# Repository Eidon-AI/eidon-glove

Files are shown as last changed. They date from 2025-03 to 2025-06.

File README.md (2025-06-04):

# eidon-glove

A robust 16-DOF hand/finger tracking wearable standard Bluetooth Human Interface Device (BLE HID) designed for humanoid teleoperation and collecting embodied AI training datasets.

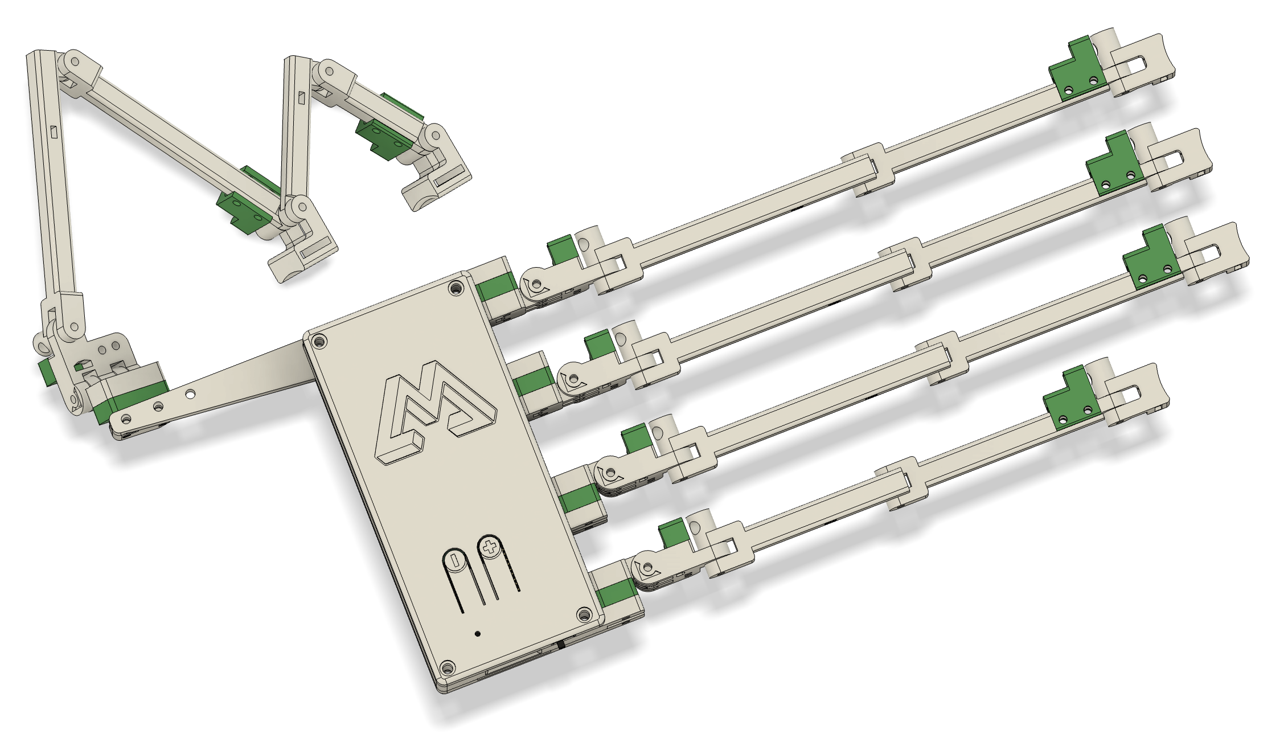
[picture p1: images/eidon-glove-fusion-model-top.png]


## Features

- **16-DOF Finger Tracking**: Full hand tracking with 16 Hall effect sensors for precise joint angle measurement
- **Wireless Connectivity**: Standard BLE HID protocol (~100Hz wireless transmission)
- **Multi-Mode Support**: Generic HID and gamepad modes with custom firmware
- **9-DOF Orientation Tracking**: Optional BNO085 IMU integration (Accelerometer/Gyro/Magnetometer)
- **Custom Hardware**: Purpose-built PCB with analog multiplexer for efficient sensor management
- **ESP32-C3 MCU**: Built-in BLE, WiFi, and battery charging capabilities
- **All-Day Battery**: 3.7V 2000mAh lithium polymer battery with power management
- **Wearable Design**: Fully 3D printable exoskeleton optimized for comfort and accuracy
- **Power Management**: Integrated power switch and LED status indicators

## Hardware Architecture

### Core Components
- **Microcontroller**: Seeed XIAO ESP32-C3 (RISC-V 32-bit @ 160MHz)
- **Sensors**: 16x Hall effect sensors + magnets for joint tracking
- **IMU**: BNO085 9-DOF sensor (optional)
- **Multiplexer**: Analog multiplexer for sensor input management
- **Battery**: 3.7V 2000mAh Li-Po with ETA4054S2F charging chip

### BOM
- Seeed XIAO ESP32-C3 [[Amazon](https://amzn.to/43tHIOO)]
- Hall Effect Sensor [[Amazon](https://amzn.to/4mQyvrq)]
- BNO085 IMU Module [[Amazon](https://amzn.to/3ZKFbNI)]
- Adjustable Hand Strap [[Amazon](https://amzn.to/4mLNEds)]
- Finger Velcro Loops [[Amazon](https://amzn.to/4kuzVpS)]
- Wire Zip Ties [[Amazon](https://amzn.to/4mFPDQp)]
- M2 Screws [[Amazon](https://amzn.to/45LmPQm)]
- Lipo Battery [[Amazon](https://amzn.to/3ZLaW9m)]
- Power Switch [[Amazon](https://amzn.to/4kTvcxY)]
- Status LED [[Amazon](https://amzn.to/43XH38d)]
- JST Connectors + Wires [[AliExpress](https://www.aliexpress.us/item/3256807031812901.html)] *(only if using custom PCB)*
- Multiplexer Module [[Amazon](https://amzn.to/3HiPO4a)] *(only if **NOT** using custom PCB)*

### Pin Configuration (XIAO ESP32-C3)

| Function | GPIO | Pin Label | Notes |
|---|---|---|---|
| **Multiplexer Control** |
| S0 | 10 | D10 | Multiplexer select bit 0 |
| S1 | 9 | D9 | Multiplexer select bit 1 |
| S2 | 6 | D4 | Multiplexer select bit 2 |
| S3 | 7 | D5 | Multiplexer select bit 3 |
| **User Interface** |
| Boot Button | 9 | D9 | Built-in XIAO button |
| Mode Button | 10 | D10 | PCB-mounted button |
| Status LED | 5 | D3 | Power/status indicator |
| **BNO085 IMU (Optional)** |
| I2C SDA | 21 | D6/TX | IMU data line |
| I2C SCL | 20 | D7/RX | IMU clock line |

## BNO085 IMU Integration (Optional)

The BNO085 9-DOF IMU provides orientation tracking to complement finger position data. This is an optional component that can be added for enhanced hand tracking capabilities.

### BNO085 Wiring

**I2C Connection:**
- **SDA**: GPIO 21 (D6/TX) - I2C Data line
- **SCL**: GPIO 20 (D7/RX) - I2C Clock line  
- **VCC**: 3.3V power supply
- **GND**: Ground connection
- **I2C Address**: 0x4B (default)

**Optional Connections:**
- **RST**: Not currently implemented (software reset used instead)
- **INT**: Interrupt pin (not used in current implementation)

### Important Notes

⚠️ **Multiplexer Pin Conflicts**: The current codebase has these remaining pin assignment conflicts:

1. **Button Conflicts**: Boot button (GPIO 9) and Mode button (GPIO 10) conflict with multiplexer pins S1 and S0

### BNO085 Software Configuration

The IMU is configured for:
- **Sensor Fusion**: Game Rotation Vector mode
- **Update Rate**: 200Hz (5ms intervals)  
- **Auto-Detection**: System continues operation if IMU is not connected
- **Data Output**: Quaternion format for orientation representation

Breakout Board Recommendation:

- GY-BNO085 Module [[Amazon](https://www.amazon.com/Teyleten-Robot-BNO085-Accuracy-Nine-Axis/dp/B0CL26J81F)]

## Getting Started

### Prerequisites
- PlatformIO IDE extension
- 3D printer for mechanical components
- PCB manufacturing (or breadboard for prototyping)
- Components listed in BOM (see PCB directory)

### Build Instructions
1. Clone this repository
2. Open firmware project in PlatformIO
3. Install dependencies (automatically handled by platformio.ini)
4. Build and upload to XIAO ESP32-C3
5. Assemble mechanical components
6. Calibrate sensors using built-in calibration mode

### Firmware Dependencies
- **ResponsiveAnalogRead** ^1.2.1: Sensor input filtering  
- **NimBLE-Arduino** ^1.4.1: Bluetooth Low Energy
- **Adafruit BNO08x** ^1.2.3: IMU sensor library

## Web Hand Visualizer

The eidon-glove includes a comprehensive web-based visualizer for real-time hand tracking data visualization and analysis.

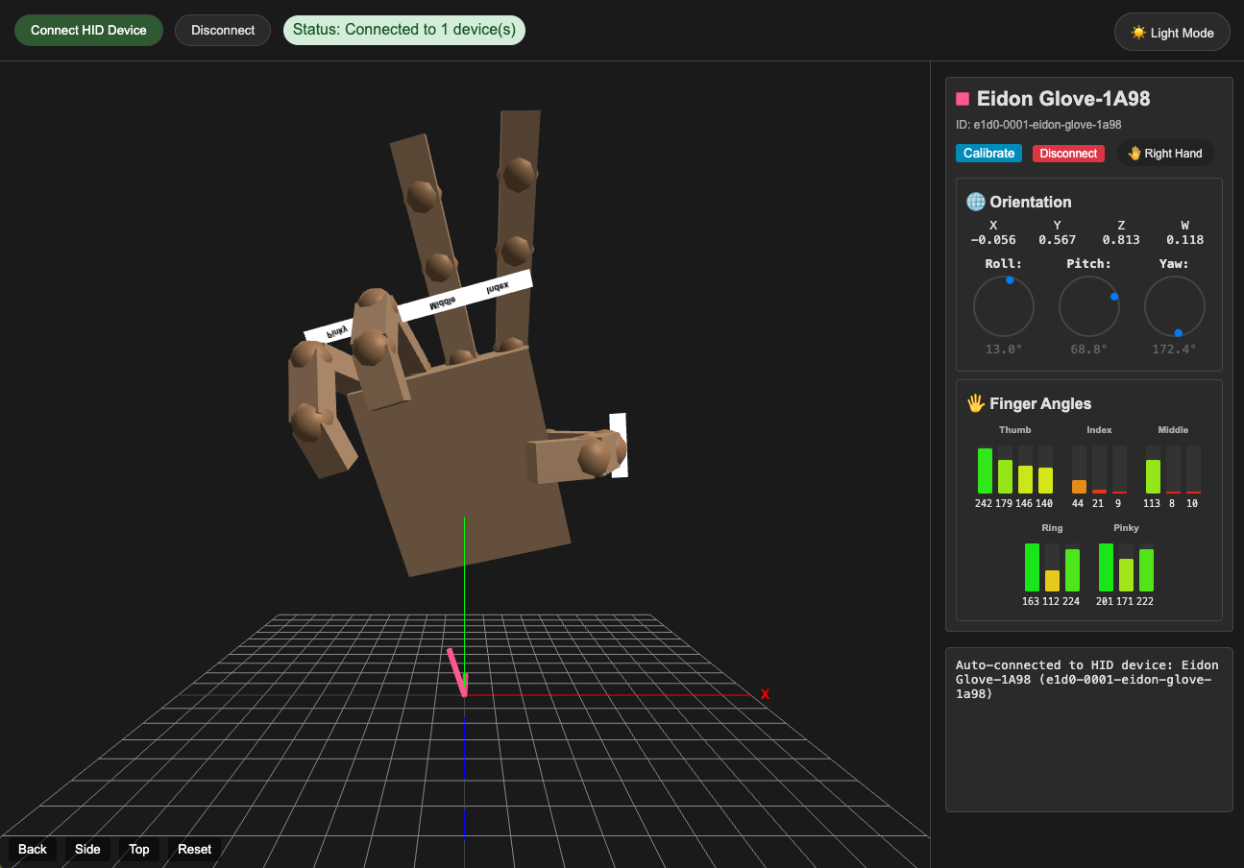
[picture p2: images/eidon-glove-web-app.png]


### What It Is

A browser-based 3D hand visualization tool that:
- **Real-time 3D Hand Model**: Displays a detailed 3D hand that mirrors your glove movements
- **IMU Orientation Tracking**: Shows precise hand orientation using quaternion data from the BNO085 IMU
- **16-DOF Finger Tracking**: Visualizes all finger joint movements with color-coded angle displays
- **Multi-Device Support**: Can connect to multiple gloves and trackers simultaneously
- **Data Recording & Playback**: Record hand movements and play them back for analysis

### Key Features

- **🎯 Gimbal-Lock Free**: Stable orientation tracking without axis flipping at extreme angles
- **🔄 Auto-Reconnect**: Automatically reconnects to previously paired devices on page refresh  
- **🎨 Color-Coded Visualization**: Device-specific colors for easy identification
- **📊 Real-Time Data**: Live quaternion values, Euler angles, and joint positions
- **🎮 HID Protocol**: Uses standard Web HID API for direct browser connection
- **💾 Session Recording**: Capture and save hand movement sequences

### How to Use

1. **Open the Web App**: Navigate to `/web/index.html` in a modern browser (Chrome/Edge recommended)
2. **Connect Your Glove**: Click "Connect" and select your eidon-glove from the HID device list
3. **Calibrate**: Use the "Calibrate" button to zero the sensor baseline
4. **Visualize**: Watch the 3D hand model mirror your real hand movements in real-time

### Browser Requirements

- **Chrome 89+** or **Edge 89+** (Web HID API support required)
- **HTTPS Connection** (required for Web HID API)
- **Modern GPU** (WebGL support for 3D rendering)

### Technical Details

- **Communication**: Web HID API for direct glove communication
- **3D Rendering**: Three.js for WebGL-based hand visualization  
- **Coordinate System**: Optimized quaternion mapping `(x, z, -y, w)` for stable orientation
- **Update Rate**: ~60fps visualization with real-time sensor data
- **Data Format**: 24-byte HID reports containing joint angles + quaternion data

### Files

```
web/

```

The web visualizer provides an intuitive way to validate glove functionality, debug sensor issues, and demonstrate the full capabilities of the eidon-glove system.

## Project Structure

```
eidon-glove/
├── firmware/          # ESP32-C3 firmware (PlatformIO)
│   ├── src/           # Main source code
│   ├── lib/           # Custom libraries
│   └── platformio.ini # Build configuration
├── pcb/               # KiCad PCB design files
├── cad/               # 3D printable components
├── web/               # Web interface (if applicable)
│   ├── index.html         # Main web interface
│   ├── script.js          # Core visualization logic
│   ├── style.css          # UI styling
│   ├── tetris.html    # Simple Tetris game demo
│   └── piano.html     # Simple five key piano demo
└── images/            # Documentation images
```

## Inspired By

This project builds upon excellent open-source work:
- **[Project-Homunculus](https://github.com/nepyope/Project-Homunculus)**: Original 3D models and mechanical design
- **[finger-tracker](https://github.com/max-titov/finger-tracker)**: Original firmware architecture
- **[glove-v3](https://github.com/max-titov/glove-v3)**: Current PCB design foundation

## Contributing

Contributions are welcome! Please:
1. Fork the repository
2. Create a feature branch
3. Make your changes
4. Test thoroughly
5. Submit a pull request

## License

This project is released under an open-source license. See individual component repositories for specific licensing terms.

---

**Status**: Active development - hardware tested, firmware functional, documentation in progress.

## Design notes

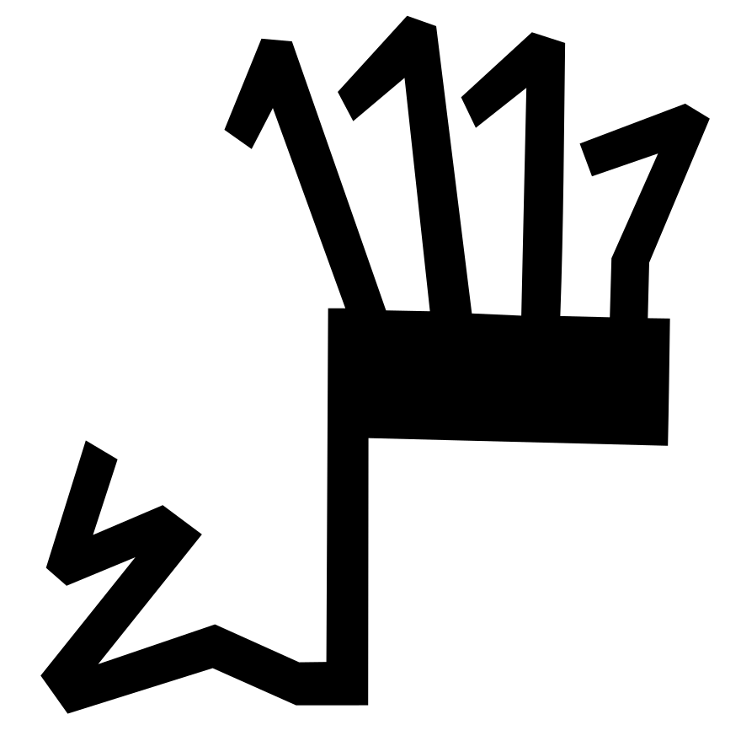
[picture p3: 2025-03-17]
pcb/graphics/glove-v1.png

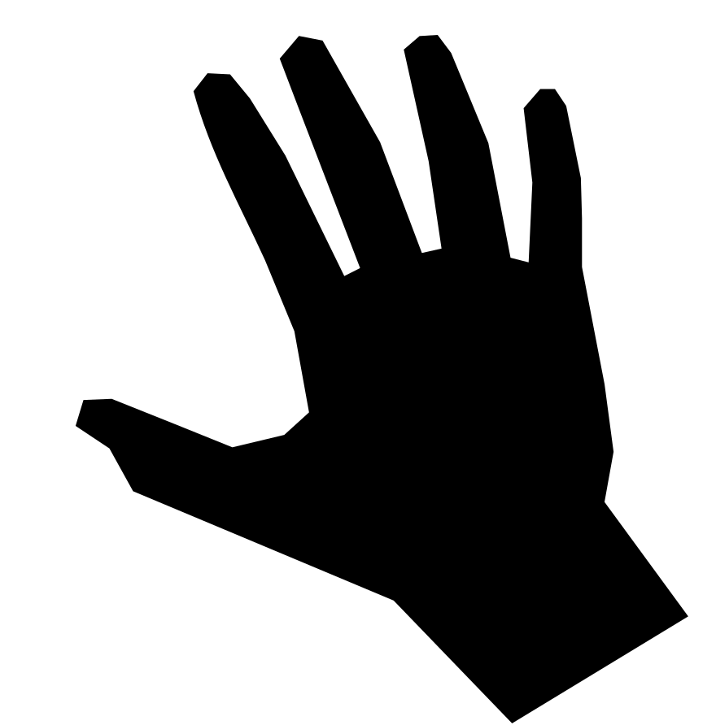
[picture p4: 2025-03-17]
pcb/graphics/hand.png

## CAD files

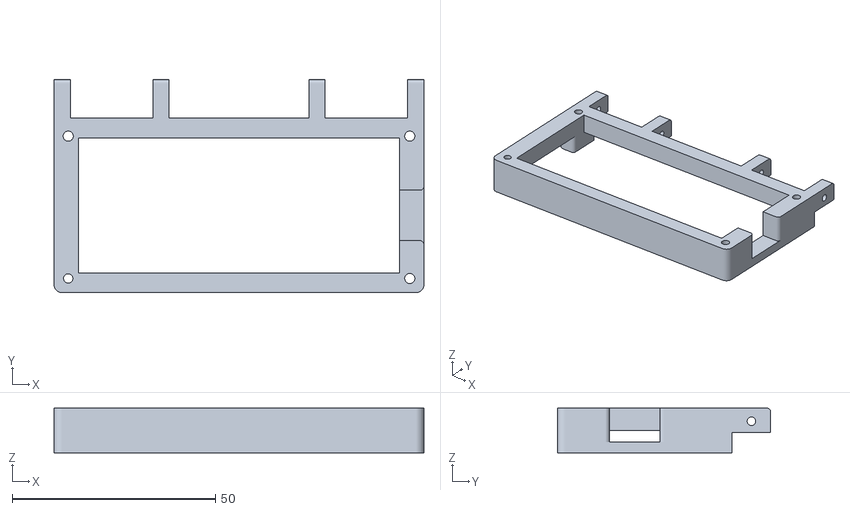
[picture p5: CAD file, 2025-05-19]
cad/palm_body.stl
91.0 x 52.5 x 11.1

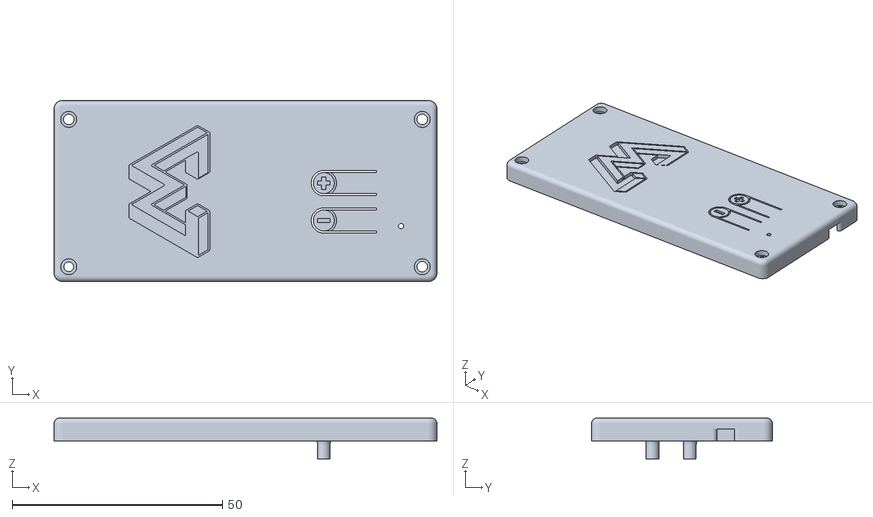
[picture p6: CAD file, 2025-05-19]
cad/palm_lid.stl
91.0 x 43.0 x 9.71

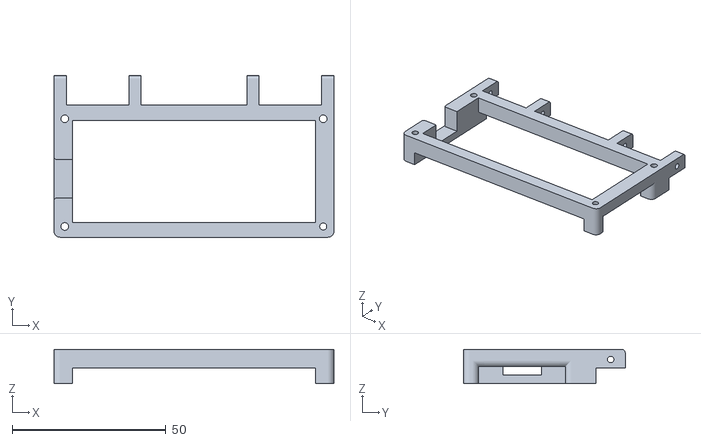
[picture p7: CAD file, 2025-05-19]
cad/palm_body_left.stl
91.0 x 52.5 x 11.1

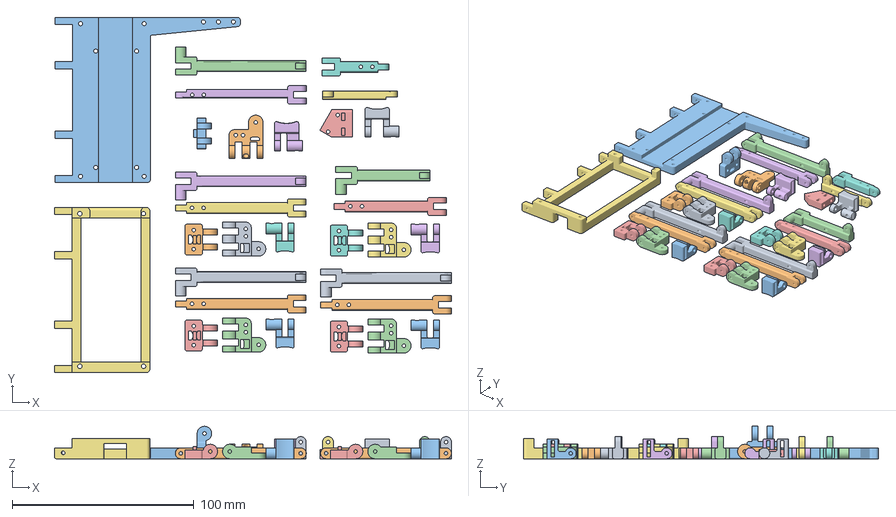
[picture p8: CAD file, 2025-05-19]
cad/EIDON_GLOVE_LEFT.3mf
218.5 x 195.5 x 17.9 mm
finger_pip_1.stl x 4
finger_pip_2.stl x 3
finger_dip_2.stl x 4
finger_mcp_3.stl x 4
finger_mcp2.stl x 4
palm_base.stl
thumb_mcp_holder.stl
thumb_pip_2.stl
thumb_ip_1.stl
thumb_ip_2.stl
thumb_ip_3.stl
thumb_mcp_3.stl
thumb_mcp_2.stl
pinky_pip_1.stl
pinky_pip_2.stl
thumb_dip_2.stl
palm_lid_alt.stl

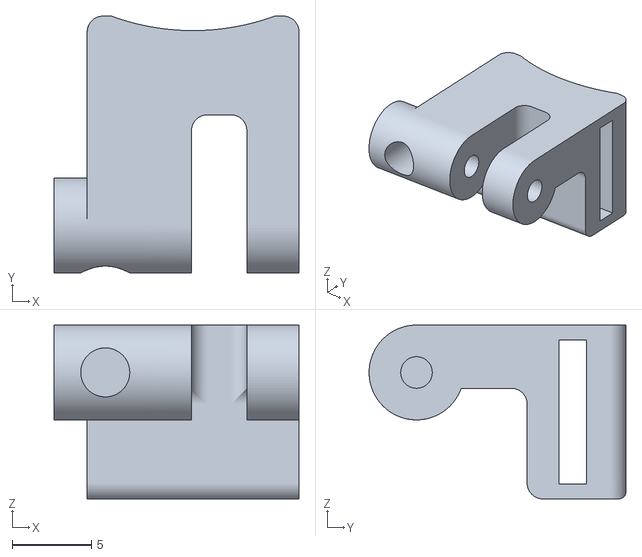
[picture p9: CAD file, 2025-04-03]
cad/thumb_dip_2.stl
15.5 x 16.2 x 11.0

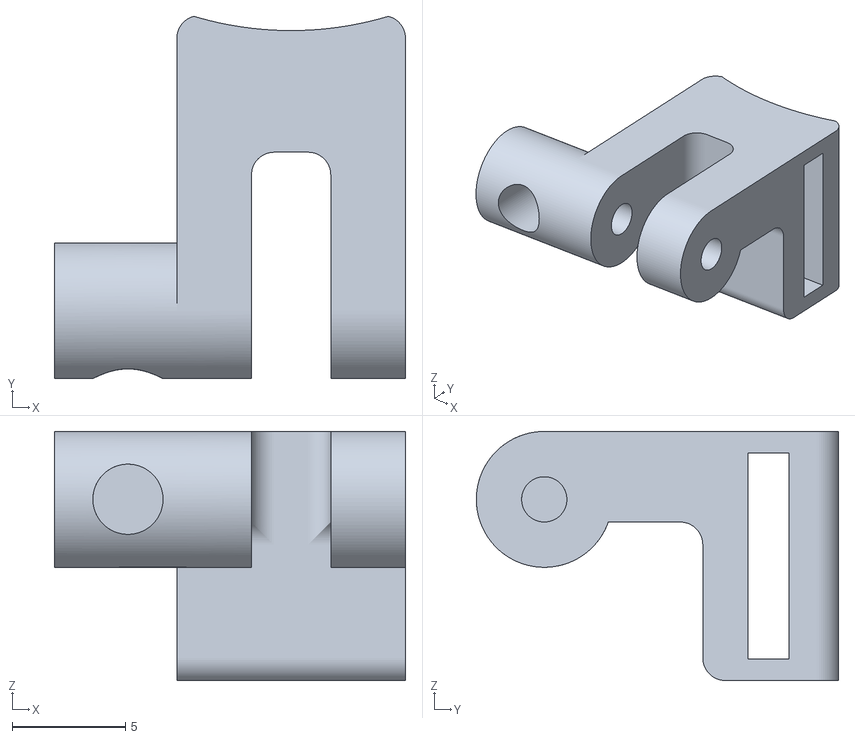
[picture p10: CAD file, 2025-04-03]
cad/finger_dip_2.stl
15.5 x 16.0 x 11.0

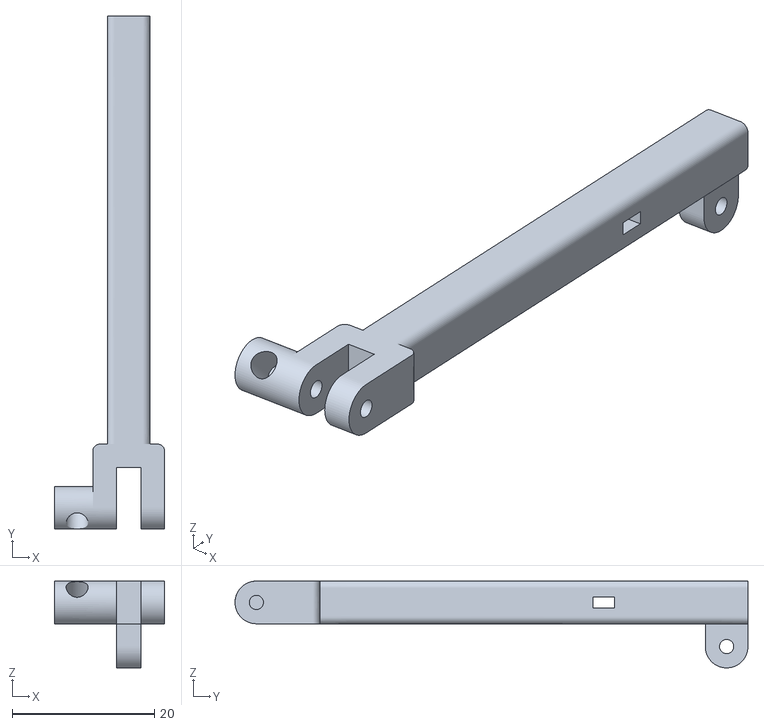
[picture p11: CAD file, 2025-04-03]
cad/thumb_pip_1.stl
15.5 x 72.1 x 12.2

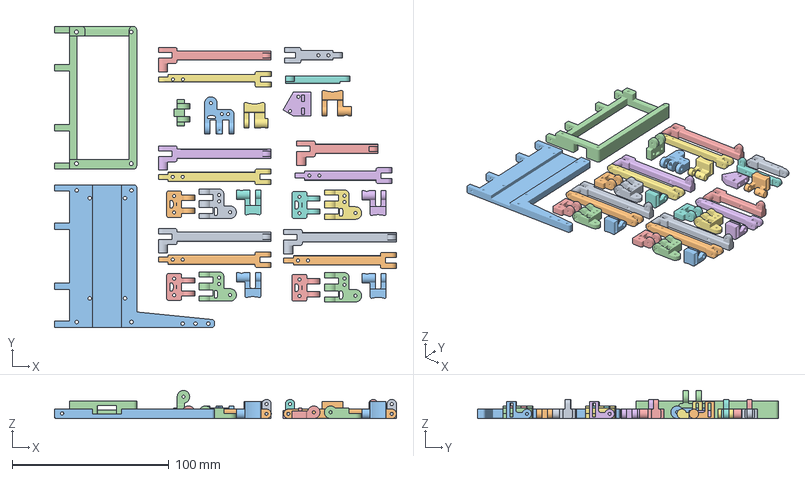
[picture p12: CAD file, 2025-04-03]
cad/EIDON_GLOVE_RIGHT.3mf
218.3 x 192.1 x 17.9 mm
finger_pip_1.stl x 4
finger_pip_2.stl x 3
finger_dip_2.stl x 4
finger_mcp_3.stl x 4
finger_mcp2.stl x 4
palm_base.stl
palm_lid.stl
thumb_mcp_holder.stl
thumb_pip_2.stl
thumb_ip_1.stl
thumb_ip_2.stl
thumb_ip_3.stl
thumb_mcp_3.stl
thumb_mcp_2.stl
pinky_pip_1.stl
pinky_pip_2.stl
thumb_dip_2.stl

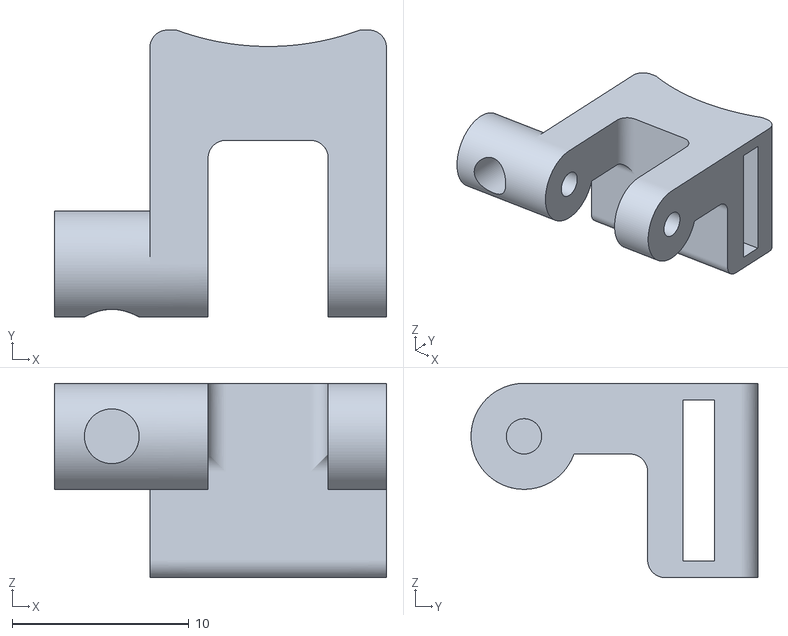
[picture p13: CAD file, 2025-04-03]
cad/thumb_ip_3.stl
18.8 x 16.2 x 11.0

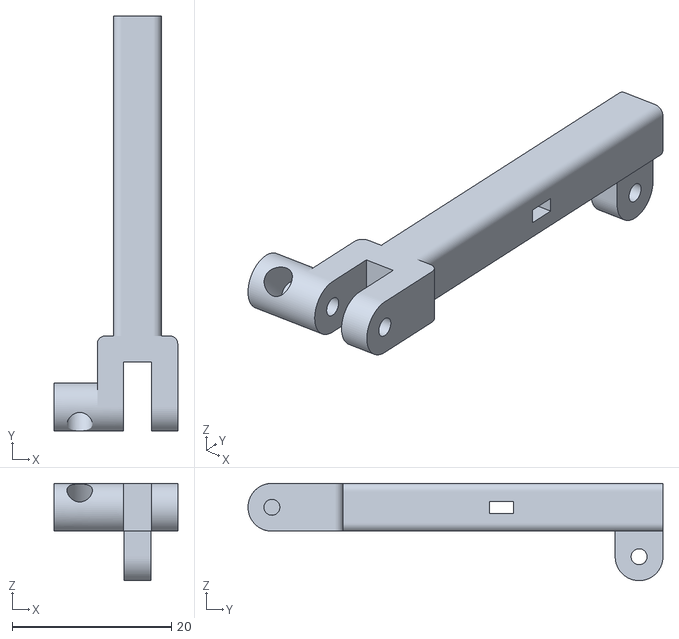
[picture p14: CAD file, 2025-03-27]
cad/pinky_pip_1.stl
15.5 x 52.1 x 12.2

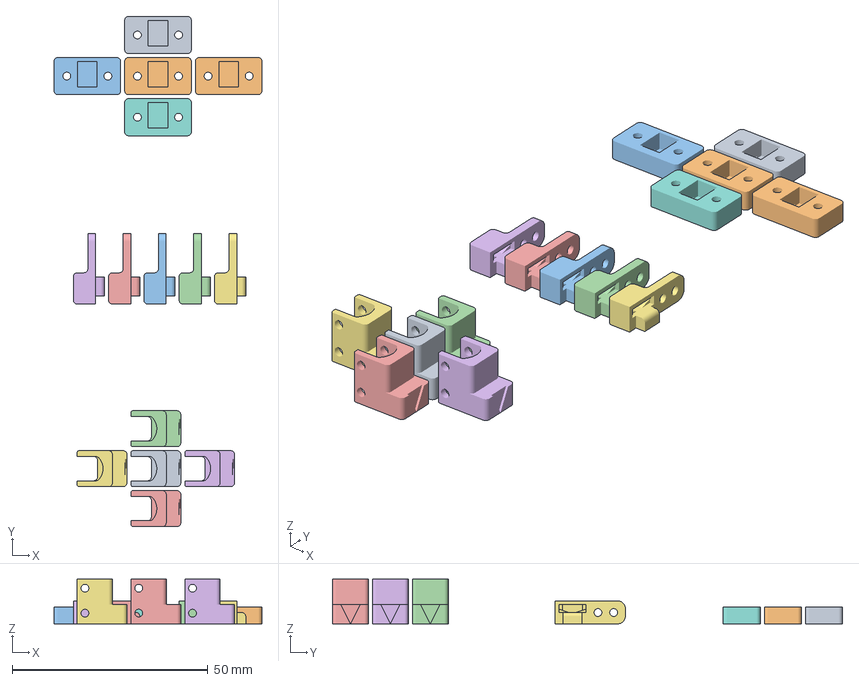
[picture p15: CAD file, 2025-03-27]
cad/EIDON_GLOVE_SENSORS.3mf
53.1 x 130.3 x 11.5 mm
finger_dip_1.stl x 5
finger_mcp_1.stl x 5
finger_mcp_4.stl x 5

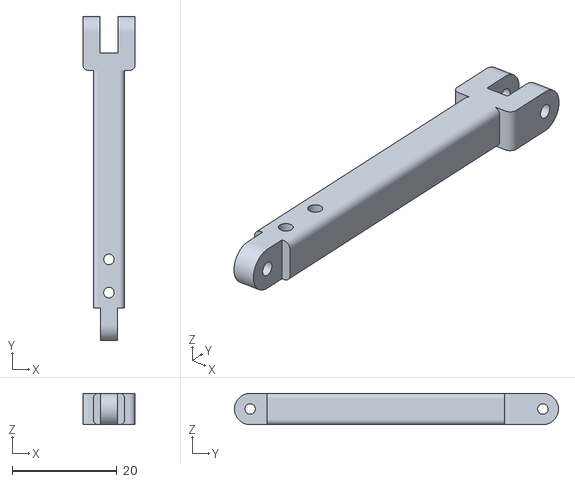
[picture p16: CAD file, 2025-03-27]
cad/pinky_pip_2.stl
10.0 x 62.0 x 6.00

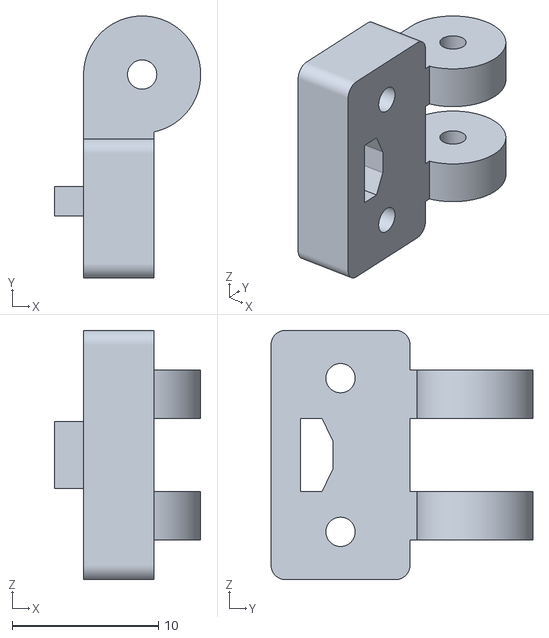
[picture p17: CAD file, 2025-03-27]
cad/thumb_mcp_2.stl
10.00 x 17.9 x 17.0

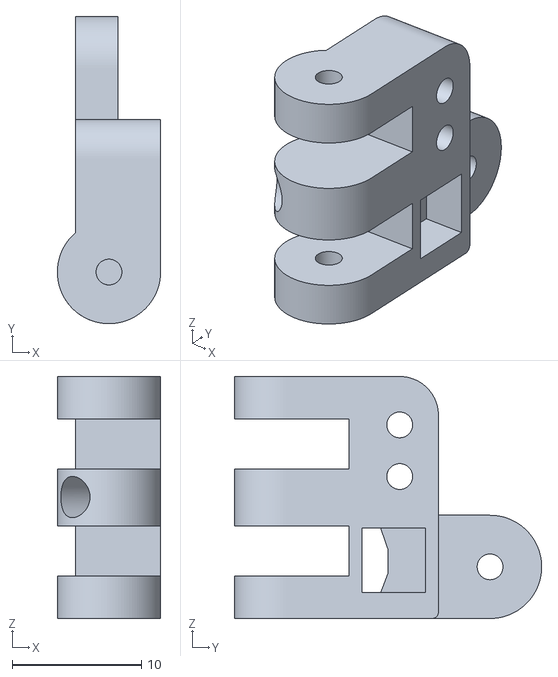
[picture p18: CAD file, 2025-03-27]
cad/thumb_mcp_3.stl
8.00 x 23.8 x 18.8

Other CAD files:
cad/palm_lid_left.stl
cad/palm_lid_blank.stl
cad/finger_mcp_1.stl
cad/thumb_pip_2.stl
cad/EIDON_FINGER.f3d
cad/EIDON_THUMB.f3d
cad/finger_dip_1.stl
cad/finger_mcp_2.stl
cad/finger_mcp_3.stl
cad/finger_mcp_4.stl
cad/finger_pip_1.stl
cad/finger_pip_2.stl
cad/palm_base.stl
cad/thumb_ip_1.stl
cad/thumb_ip_2.stl
cad/thumb_mcp_holder.stl

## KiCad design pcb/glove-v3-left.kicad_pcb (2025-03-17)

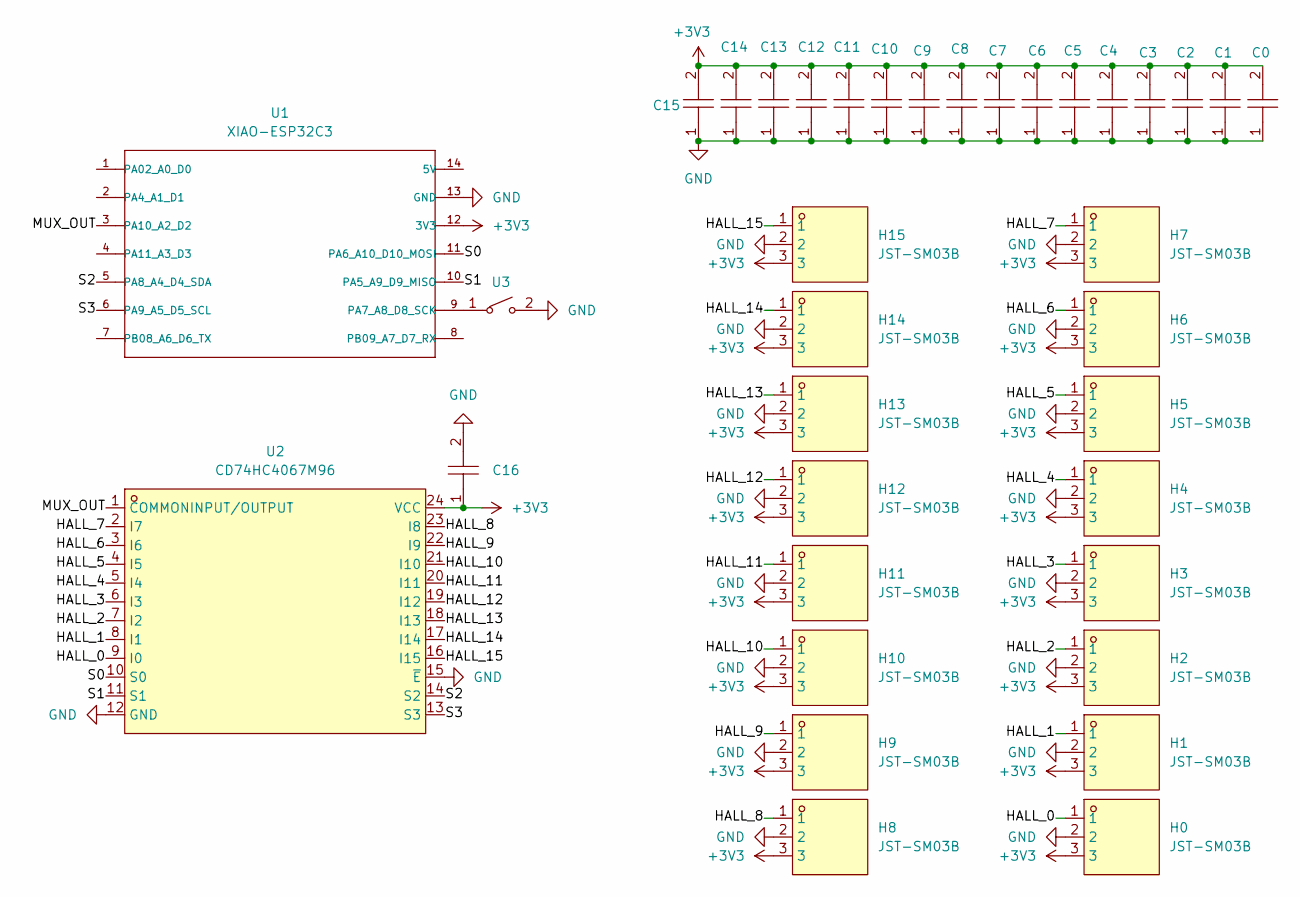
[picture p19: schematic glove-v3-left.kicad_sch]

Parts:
C0, C1, C2, C3, C4, C5, C6, C7, C8, C9, C10, C11, C12, C13, C14, C15, C16: C-0402-0.1uF-16V; C0402; LCSC Part C1525
H0, H1, H2, H3, H4, H5, H6, H7, H8, H9, H10, H11, H12, H13, H14, H15: JST-SM03B; CONN-SMD_SM03B-SRSS-TB-LF-SN-P; LCSC Part C160403
U1: XIAO-ESP32C3; MOUDLE14P-SMD-2.54-21X17.8MM
U2: CD74HC4067M96; SOIC-24_L15.4-W7.5-P1.27-LS10.3-BL; LCSC Part C496123
U3: 2.5x3mm-BUTTON; KEY-SMD_L3.0-W2.5-LS4.0_TD-1183SN; LCSC Part C2905193

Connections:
+3V3: C0.2, C1.2, C2.2, C3.2, C4.2, C5.2, C6.2, C7.2, C8.2, C9.2, C10.2, C11.2, C12.2, C13.2, C14.2, C15.2, C16.1, H0.3, H1.3, H2.3, H3.3, H4.3, H5.3, H6.3, H7.3, H8.3, H9.3, H10.3, H11.3, H12.3, H13.3, H14.3, H15.3, U1.12 (3V3), U2.24 (VCC)
/HALL_0: H0.1, U2.9 (I0)
/HALL_1: H1.1, U2.8 (I1)
/HALL_2: H2.1, U2.7 (I2)
/HALL_3: H3.1, U2.6 (I3)
/HALL_4: H4.1, U2.5 (I4)
/HALL_5: H5.1, U2.4 (I5)
/HALL_6: H6.1, U2.3 (I6)
/HALL_7: H7.1, U2.2 (I7)
/HALL_8: H8.1, U2.23 (I8)
/HALL_9: H9.1, U2.22 (I9)
/HALL_10: H10.1, U2.21 (I10)
/HALL_11: H11.1, U2.20 (I11)
/HALL_12: H12.1, U2.19 (I12)
/HALL_13: H13.1, U2.18 (I13)
/HALL_14: H14.1, U2.17 (I14)
/HALL_15: H15.1, U2.16 (I15)
/MUX_OUT: U1.3 (PA10_A2_D2), U2.1 (COMMONINPUT/OUTPUT)
/S0: U1.11 (PA6_A10_D10_MOSI), U2.10 (S0)
/S1: U1.10 (PA5_A9_D9_MISO), U2.11 (S1)
/S2: U1.5 (PA8_A4_D4_SDA), U2.14 (S2)
/S3: U1.6 (PA9_A5_D5_SCL), U2.13 (S3)
GND: C0.1, C1.1, C2.1, C3.1, C4.1, C5.1, C6.1, C7.1, C8.1, C9.1, C10.1, C11.1, C12.1, C13.1, C14.1, C15.1, C16.2, H0.2, H1.2, H2.2, H3.2, H4.2, H5.2, H6.2, H7.2, H8.2, H9.2, H10.2, H11.2, H12.2, H13.2, H14.2, H15.2, U1.13 (GND), U2.12 (GND), U2.15 (~E), U3.2
unnamed: U1.9 (PA7_A8_D8_SCK), U3.1

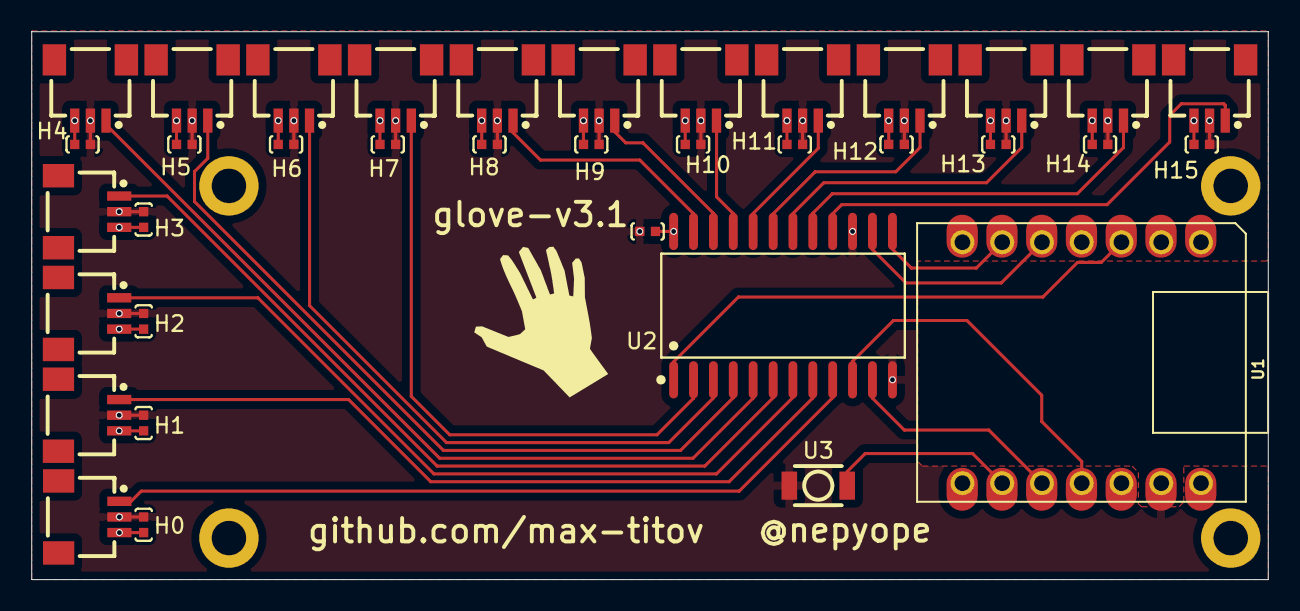
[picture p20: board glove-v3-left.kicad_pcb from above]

Board: 4 copper layers, 79.0 x 35.0 mm, 36 parts (0 on the bottom side), 24 nets.

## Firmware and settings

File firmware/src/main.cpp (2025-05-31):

#include <NimBLEDevice.h>
#include <NimBLEServer.h>
#include <NimBLEUtils.h>
#include <NimBLEHIDDevice.h>
#include <NimBLECharacteristic.h>
#include "BNO085.h"
#include "FingerTracking.h"
#include "HallEffectSensors.h"
#include <Preferences.h>

// Set to true for left hand, false for right hand
#define IS_LEFT_HAND 0

// Vendor and Product IDs
#define VENDOR_ID  0xE1D0 // Eidon AI vendor ID
#define PRODUCT_ID 0x0001 // Eidon Glove v1 product ID

// Define the number of axes we'll use
#define NUM_JOINTS 16  // We want all 16 joints

// Define the button pin for the Xiao ESP32-C3
#define BUTTON_BOOT_PIN  9 // user button on Xiao
#define BUTTON_MODE_PIN  10 // button on pcb

// Define the LED pin
#define LED_PIN  5

// Add these at the top of your file with other global variables
#define BUTTON_COUNT 5                  // Number of finger buttons we're tracking
#define PRESS_THRESHOLD 150             // Absolute threshold for press detection
#define RELEASE_THRESHOLD 130           // Threshold for release detection
#define NOISE_TOLERANCE 5               // Tolerance for signal noise
#define DEBOUNCE_TIME 50                // Very short debounce time for responsiveness
#define POSITION_HISTORY_SIZE 10       // Number of samples to track for position changes
#define HISTORY_SIZE 3                  // Small history size for minimal lag

// Define deadzone parameters
#define DEADZONE 32                   // Size of the deadzone (in output units, 0-255)
#define ANALOG_CENTER 127             // Center value for analog stick

// LED status variables
unsigned long ledLastUpdate = 0;
// LED patterns
enum LEDPattern {
    LED_ADVERTISING,  // Strobing brightness when advertising
    LED_CONNECTED,    // Fast blinking when connected
    LED_IMU_RESET     // Solid LED when resetting IMU
};
LEDPattern currentLEDPattern = LED_ADVERTISING;
unsigned long imuResetStartTime = 0;
const unsigned long IMU_RESET_DURATION = 300; // Solid LED duration in ms
int ledBrightness = 0;
bool ledState = false;

// Simple timer for debugging LED
unsigned long debugLedTimer = 0;
const unsigned long LED_FLASH_INTERVAL = 50; // Very slow flash for debugging

// LED brightness settings
#define LED_DIM_BRIGHTNESS 50  // Dim brightness level (0-255) when connected

// Button hold calibration reset constants
#define CALIBRATION_RESET_HOLD_TIME 3000  // Hold for 3 seconds to reset calibration
bool buttonHoldInProgress = false;
unsigned long buttonHoldStartTime = 0;
bool calibrationResetTriggered = false;

/* One top-level application collection, Usage = Gamepad                    */
/*  ├─ Input  (Button/Flags, Finger Angle Bytes, Quaternion)                */
/*  ├─ Output (Vendor byte)                                                 */
/*  └─ Feature(RGB)                                                         */

const uint8_t hid_report_descriptor[] = {

    /* -----------------------------------------------------------------------
     * Top-level collection : sensor orientation + vendor channel, ID = 1
     * ---------------------------------------------------------------------*/
    0x05, 0x01,            // UsagePage (Generic Desktop)
    0x09, 0x05,            // Usage (Gamepad)
    0xA1, 0x01,            // Collection (Application)

        0x85, 0x01,        //   Report ID (1)

        /* --- button flags : 16-bits ------------------------------------ */
        0x05, 0x09,        // Usage Page (Button)
        0x19, 0x01,        // Usage Minimum (Button 1)
        0x29, 0x10,        // Usage Maximum (Button 16)
        0x15, 0x00,        // Logical Minimum (0)
        0x25, 0x01,        // Logical Maximum (1)
        0x75, 0x01,        // Report Size (1)
        0x95, 0x10,        // Report Count (16)
        0x81, 0x02,        // Input (Data, Variable, Absolute)
        
        /* --- finger angles : 16 8-bit axes ------------------------------ */
        0x05, 0x01,        // Usage Page (Generic Desktop)
        0x09, 0x30,        // Usage (X)
        0x09, 0x31,        // Usage (Y)
        0x09, 0x32,        // Usage (Z)
        0x09, 0x33,        // Usage (Rx)
        0x09, 0x34,        // Usage (Ry)
        0x09, 0x35,        // Usage (Rz)
        0x09, 0x36,        // Usage (Slider)
        0x09, 0x37,        // Usage (Dial)
        0x09, 0x38,        // Usage (Wheel)
        0x09, 0x39,        // Usage (Hat switch)
        0x09, 0x3A,        // Usage (Counted Buffer)
        0x09, 0x3B,        // Usage (Byte Count)
        0x09, 0x3C,        // Usage (Motion Wakeup)
        0x09, 0x3D,        // Usage (Start)
        0x09, 0x3E,        // Usage (Select)
        0x09, 0x3F,        // Usage (Vector)
        0x15, 0x00,        // Logical Minimum (0)
        0x26, 0xFF, 0x00,  // Logical Maximum (255)
        0x75, 0x08,        // Report Size (8)
        0x95, 0x10,        // Report Count (16)
        0x81, 0x02,        // Input (Data, Variable, Absolute)

        /* --- quaternion orientation (Sensor page) ------------------------ */
        0x05, 0x20,                    // Usage Page (Sensor)
        0x09, 0x80,                    // Usage (Orientation)
        /* --- 4×16-bit quaternion components (i, j, k, real) -------------- */
        0x0A, 0x83, 0x04,              // Usage 0x0483 – Data Field: Quaternion
        0x75, 0x10,                    // Report Size (16)
        0x95, 0x04,                    // Report Count (4)
        0x17, 0x00, 0x00, 0x00, 0x00,  // Logical Minimum 0 (32-bit)
        0x27, 0xFF, 0xFF, 0x00, 0x00,  // Logical Maximum 65535 (32-bit)
        0x81, 0x02,                    // Input (Data,Var,Abs)

        /* ------------------------------------------------------------------
        * Vendor-defined channel : Output (1 byte) – command interface
        * ---------------------------------------------------------------- */
        0x06, 0x00, 0xFF,     // Usage Page (Vendor 0xFF00)
        0x09, 0x01,           // Usage 1
        0x15, 0x00,           // Logical Minimum (0)
        0x26, 0xFF, 0x00,     // Logical Maximum (255)
        0x75, 0x08,           // Report Size (8)
        0x95, 0x01,           // Report Count (1)
        0x91, 0x02,           // Output (Data,Var,Abs)

        /* ------------------------------------------------------------------
        * Vendor-defined Feature report : saved RGB (3 bytes)
        * ---------------------------------------------------------------- */
        0x09, 0x02,           // Usage (Vendor 2)
        0x15, 0x00,           // Logical Minimum (0)
        0x26, 0xFF, 0x00,     // Logical Maximum (255)
        0x95, 0x03,           // Report Count 3
        0x75, 0x08,           // Report Size 8
        0xB1, 0x02,           // Feature (Data,Var,Abs)

    0xC0                  // End Application Collection
};

// Variables to store joint values and button state
// uint8_t reportData[NUM_JOINTS + 2] = {0}; // +1 for button state

// BLE objects
NimBLEServer* pServer = nullptr;
NimBLEHIDDevice* hid = nullptr;
NimBLECharacteristic* inputGamepad = nullptr;
NimBLECharacteristic* outputGamepad = nullptr;
NimBLECharacteristic* featureColor = nullptr;
bool deviceConnected = false;
bool oldDeviceConnected = false;

// Persistent storage
Preferences prefs;

// Device color (RGB)
uint8_t deviceColor[3] = {0xFF, 0xFF, 0xFF};

// Define an enum for the different modes
enum ControlMode {
    GAME_MODE = 0,       // Mapped controls for gameplay
    RAW_ANGLES_MODE = 1, // Show all raw angle values
    // Add more modes as needed in the future
    MODE_COUNT           // Always keep this as the last item to track the number of modes
};

// Add this at the top of your file with other global variables
ControlMode currentMode = RAW_ANGLES_MODE;
bool modeJustChanged = true;         // Flag to indicate when mode has just changed

// Structure to track finger motion for button detection
struct FingerButtonState {
    int32_t baselineAngle;    // Baseline angle (calibrated at start)
    int32_t prevAngle;        // Previous angle reading
    bool isPressed;           // Current button state
    unsigned long lastChange; // Timestamp of last state change
};

// Array to track state for each finger button
FingerButtonState fingerButtons[BUTTON_COUNT];

// Finger indices for button detection
const int fingerIndices[BUTTON_COUNT] = {2, 5, 8, 11, 14}; // Thumb, Index, Middle, Ring, Pinky

// Track recent motion history
int32_t angleHistory[BUTTON_COUNT][HISTORY_SIZE];

// Track average motion range for each finger
int32_t avgMotionRange[BUTTON_COUNT] = {0};

// Define arrays for finger-specific thresholds
const int32_t PRESS_THRESHOLDS[BUTTON_COUNT] = {
    120,  // Thumb 0 (Thumb)
    200,  // Index 0 (Index) - Standard threshold
    200,  // Middle 1 (Middle) - Higher threshold (less sensitive)
    200,  // Ring 2 (Ring) - Medium-high threshold
    200   // Pinky 3 (Pinky) - Lower threshold (more sensitive)
};

const int32_t RELEASE_THRESHOLDS[BUTTON_COUNT] = {
    110,  // Thumb 0 (Thumb)
    192,  // Index 1 (Index)
    192,  // Middle 2 (Middle)
    192,  // Ring 3 (Ring)
    192,   // Pinky 4 (Pinky)
};

// Initialize the finger button tracking
void initFingerButtons() {
    for (int i = 0; i < BUTTON_COUNT; i++) {
        fingerButtons[i].baselineAngle = 0;  // Will be calibrated later
        fingerButtons[i].prevAngle = 0;
        fingerButtons[i].isPressed = false;
        fingerButtons[i].lastChange = 0;
        
        // Initialize history array
        for (int j = 0; j < HISTORY_SIZE; j++) {
            angleHistory[i][j] = 0;
        }
    }
}

// Server callbacks
class ServerCallbacks : public NimBLEServerCallbacks {
    void onConnect(NimBLEServer* pServer) {
        Serial.println("Client connected!");
        deviceConnected = true;
    };

    void onDisconnect(NimBLEServer* pServer) {
        Serial.println("Client disconnected");
        deviceConnected = false;
    };
};

// Security callback to accept pairing requests
class SecurityCallbacks : public NimBLESecurityCallbacks {
    uint32_t onPassKeyRequest() {
        Serial.println("Passkey request");
        return 123456; // Just use a simple passkey for testing
    }

    void onPassKeyNotify(uint32_t pass_key) {
        Serial.print("Passkey Notify: ");
        Serial.println(pass_key);
    }

    bool onConfirmPIN(uint32_t pass_key) {
        Serial.print("Confirm PIN: ");
        Serial.println(pass_key);
        return true;
    }

    bool onSecurityRequest() {
        Serial.println("Security Request");
        return true;
    }

    void onAuthenticationComplete(ble_gap_conn_desc* desc) {
        Serial.println("Authentication Complete");
        Serial.print("Secure: ");
        Serial.println(desc->sec_state.encrypted ? "Yes" : "No");
    }
};

// Function to map angle values to the 0-255 range needed for HID
uint8_t mapAngleToHID(int32_t angle, int32_t minAngle, int32_t maxAngle) {
    // Constrain the angle to the min-max range
    int32_t constrainedAngle = constrain(angle, minAngle, maxAngle);
    
    // Map to 0-255 range for HID
    return map(constrainedAngle, minAngle, maxAngle, 0, 255);
}

// Gamepad descriptor layout for buttons and axes
typedef struct {
  // Action buttons
  bool button1 : 1;
  bool button2 : 1;
  bool button3 : 1;
  bool button4 : 1;
  bool button5 : 1;
  bool button6 : 1;
  bool button7 : 1;
  bool button8 : 1;

  bool cfgbit0 : 1; // isLeftHand
  bool cfgbit1 : 1;
  bool cfgbit2 : 1;
  bool cfgbit3 : 1;
  bool cfgbit4 : 1;
  bool cfgbit5 : 1;
  bool cfgbit6 : 1;
  bool cfgbit7 : 1;

  // All 23 axes
  uint8_t axes[16]; // Updated to 23 total axes

  // 4 values for quaternion (w, x, y, z)
  uint16_t quaternion[4];
} GamepadReport;

// Create an instance of the gamepad report
GamepadReport gamepadReport = {0};

// Add function to convert quaternion to gamepad axis value
uint16_t quaternionToAxis(float quat_val) {
    // Map -1.0 to 1.0 to 0-65535
    return (uint16_t)((quat_val + 1.0f) * 32767.5f);
}

// Add this function before setup()
void printHIDDescriptor() {
    Serial.println("HID Report Descriptor:");
    for (size_t i = 0; i < sizeof(hid_report_descriptor); i++) {
        if (hid_report_descriptor[i] < 16) Serial.print("0");
        Serial.print(hid_report_descriptor[i], HEX);
        Serial.print(" ");
        if ((i + 1) % 8 == 0) Serial.println();
    }
    Serial.println();
    Serial.print("Total descriptor size: ");
    Serial.println(sizeof(hid_report_descriptor));
    Serial.print("GamepadReport struct size: ");
    Serial.println(sizeof(GamepadReport));
}

// Function to cycle to the next mode
void cycleToNextMode() {
    currentMode = static_cast<ControlMode>((currentMode + 1) % MODE_COUNT);
    modeJustChanged = true;
    
    // Print the new mode
    Serial.print("Mode changed to: ");
    switch (currentMode) {
        case GAME_MODE:
            Serial.println("Game Mode");
            break;
        case RAW_ANGLES_MODE:
            Serial.println("Raw Angles Mode");
            break;
        default:
            Serial.println("Unknown Mode");
            break;
    }
}

// Function to apply deadzone with proper rescaling
uint8_t applyDeadzone(int32_t rawValue, uint8_t deadzone) {
    // Center around zero for easier math
    int32_t centered = rawValue - ANALOG_CENTER;
    
    // Check if within deadzone
    if (abs(centered) <= deadzone/2) {
        return ANALOG_CENTER; // Return center value
    }
    
    // Rescale values outside deadzone to use full range
    // This ensures smooth transition from deadzone edge to max values
    if (centered > 0) {
        // Positive side (127...255)
        // Map from (deadzone/2...127) to (0...127)
        return ANALOG_CENTER + map(centered - deadzone/2, 
                                  0, 
                                  127 - deadzone/2,
                                  0, 
                                  127);
    } else {
        // Negative side (0...127)
        // Map from (-127...-deadzone/2) to (-127...0)
        return ANALOG_CENTER + map(centered + deadzone/2, 
                                  -127 + deadzone/2, 
                                  0,
                                  -127, 
                                  0);
    }
}
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
void loop() {
    // Update LED status first
    updateLEDStatus();
    
    // Check for calibration reset button hold (independent of connection state)
    bool bootButtonPressed = !digitalRead(BUTTON_BOOT_PIN);
    
    if (bootButtonPressed) {
        if (!buttonHoldInProgress) {
            // Button just pressed, start timing
            buttonHoldInProgress = true;
            buttonHoldStartTime = millis();
            calibrationResetTriggered = false;
        } else {
            // Button is being held, check if it's been long enough
            unsigned long holdDuration = millis() - buttonHoldStartTime;
            
            if (holdDuration >= CALIBRATION_RESET_HOLD_TIME && !calibrationResetTriggered) {
                // Button held long enough, reset calibration
                Serial.println("Button held for 3+ seconds - resetting hall effect calibration!");
                clearHallEffectCalibration();
                calibrationResetTriggered = true;
                
                // Flash LED rapidly to indicate reset
                for (int i = 0; i < 6; i++) {
                    digitalWrite(LED_PIN, HIGH);
                    delay(100);
                    digitalWrite(LED_PIN, LOW);
                    delay(100);
                }
            }
        }
    } else {
        if (buttonHoldInProgress) {
            // Button was released
            unsigned long holdDuration = millis() - buttonHoldStartTime;
            if (holdDuration < CALIBRATION_RESET_HOLD_TIME && !calibrationResetTriggered) {
                Serial.print("Button held for ");
                Serial.print(holdDuration);
                Serial.println("ms (need 3000ms for calibration reset)");
            }
            buttonHoldInProgress = false;
        }
    }
    
    // Handle connection state changes
    if (deviceConnected && !oldDeviceConnected) {
        // Just connected
        Serial.println("Connected - starting to send data");
        oldDeviceConnected = deviceConnected;
        
        // Force reset LED state and start fresh pattern
        digitalWrite(LED_PIN, LOW);  // Start with LED OFF
        ledState = false;
        ledLastUpdate = 0; // Force immediate update
        currentLEDPattern = LED_CONNECTED;
        Serial.println("Switching to CONNECTED LED pattern - should flash dimmed");
    }
    
    if (!deviceConnected && oldDeviceConnected) {
        // Just disconnected
        Serial.println("Disconnected - restarting advertising");
        // delay(500); // Give BLE stack time to get ready
        NimBLEDevice::startAdvertising();
        Serial.println("Advertising restarted");
        oldDeviceConnected = deviceConnected;
        currentLEDPattern = LED_ADVERTISING; // Switch to advertising LED pattern
    }
    
    // Update finger tracking data
    calcFingerAngles();

    // Update BNO085 data
    updateBNO085();

    // Send data if connected
    if (deviceConnected) {
        // Read the button state from the Xiao ESP32-C3 (for mode switching, separate from calibration reset)
        int buttonsState = !digitalRead(BUTTON_BOOT_PIN) || !digitalRead(BUTTON_MODE_PIN) << 1;
        
        // Toggle between modes on button release (but only if it wasn't a long hold for calibration reset)
        static int lastButtonState = 0;
        if (!buttonsState && lastButtonState && !calibrationResetTriggered) {  // Button was released and wasn't a calibration reset
            // cycleToNextMode();
            if (isBNO085Available()) {
                resetBNO085();
                startIMUResetPattern(); // Start IMU reset LED pattern
            }
        }
        lastButtonState = buttonsState;
        
        // Update the gamepad report structure
        // Clear all buttons first
        memset(&gamepadReport, 0, sizeof(GamepadReport));

        // Set button1 based on the physical button
        gamepadReport.button1 = buttonsState & 0x01;
        gamepadReport.button2 = buttonsState & 0x02;
        
        // Set button9 to indicate left/right hand
        gamepadReport.cfgbit0 = IS_LEFT_HAND;
        
        // Set buttons to indicate current mode (optional)
        // gamepadReport.button1 = (currentMode == GAME_MODE);
        // gamepadReport.button2 = (currentMode == RAW_ANGLES_MODE);
        
        // Process data based on the current mode
        switch (currentMode) {
            case GAME_MODE:
                // GAME MODE: Use mapped controls for gameplay

                // Update finger button states based on position changes
                updateFingerButtons();
                
                // Only update quaternion if BNO085 is available
                if (isBNO085Available()) {
                    quaternionToEuler();
                    // Map roll angle to X-axis (left/right movement)
                    gamepadReport.axes[0] = constrain(map(ypr.roll, -45, 45, 0, 255), 0, 255);
                } else {
                    // Fallback: center the axis when IMU is not available
                    gamepadReport.axes[0] = 127;  // Center position
                }

                // Set button states based on detected gestures
                gamepadReport.button1 = fingerButtons[0].isPressed; // Thumb
                gamepadReport.button2 = fingerButtons[1].isPressed; // Pinky finger
                gamepadReport.button3 = fingerButtons[2].isPressed; // Ring finger
                gamepadReport.button4 = fingerButtons[3].isPressed; // Middle finger
                gamepadReport.button5 = fingerButtons[4].isPressed; // Index finger

                // Map pitch angle to Y-axis (up/down movement)
                // gamepadReport.axes[1] = constrain(map(ypr.pitch, -45, 45, 0, 255), 0, 255);

                // Apply deadzone to both axes
                // gamepadReport.axes[0] = applyDeadzone(gamepadReport.axes[0], DEADZONE);
                // gamepadReport.axes[1] = applyDeadzone(gamepadReport.axes[1], DEADZONE);

                // Fill remaining axes with zeros or other mapped values
                for (int i = 2; i < 16; i++) {
                    gamepadReport.axes[i] = 127;
                }
                break;
                
            case RAW_ANGLES_MODE:
                // RAW ANGLES MODE: Show all raw angle values

                // Map all raw angle values directly to axes
                for (int i = 0; i < NUM_JOINTS && i < 16; i++) {
                    gamepadReport.axes[i] = mapAngleToHID(angles[i], 0, 255);
                }

                // Store quaternion values directly as 16-bit values (if BNO085 available)
                if (isBNO085Available()) {
                    gamepadReport.quaternion[0] = quaternionToAxis(quaternion_x);
                    gamepadReport.quaternion[1] = quaternionToAxis(quaternion_y);
                    gamepadReport.quaternion[2] = quaternionToAxis(quaternion_z);
                    gamepadReport.quaternion[3] = quaternionToAxis(quaternion_w);
                } else {
                    // Fallback: identity quaternion when IMU is not available
                    gamepadReport.quaternion[0] = quaternionToAxis(0.0f);  // x
                    gamepadReport.quaternion[1] = quaternionToAxis(0.0f);  // y  
                    gamepadReport.quaternion[2] = quaternionToAxis(0.0f);  // z
                    gamepadReport.quaternion[3] = quaternionToAxis(1.0f);  // w (identity)
                }
                break;
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

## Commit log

2025-03-18 updates latestest iteration of 3d printable parts and includes Fusion Archive and Bambu export files
    [EIDON_GLOVE.3mf, finger_mcp_1.stl, finger_mcp_3.stl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]
2025-03-18 moar 3d model updates
    [EIDON_GLOVE.3mf, finger_mcp2.stl, finger_mcp_1.stl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]
2025-03-20 adds unique thumb 3d printed parts and updates base model files
    [EIDON_GLOVE.3mf, finger_mcp_4.stl, thumb_ip_1.stl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]
2025-03-21 updates thumb and several slight changes to finger 3d model parts; updates firmware for custom PCB esp32 pins assigned to MUX
    [EIDON_GLOVE.3mf, finger_mcp2.stl, finger_mcp_1.stl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]
2025-03-27 refining angle calculations for glove v3
    [EIDON_GLOVE.3mf, EIDON_GLOVE_SENSORS.3mf, pinky_pip_1.stl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]
2025-03-27 fix web view for glove v3
    [main.cpp]
2025-04-03 updates thumb models; adds gyro sensor support; updates web visualizer to use web hid
    [EIDON_GLOVE.3mf, finger_dip_2.stl, thumb_dip_2.stl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]
2025-04-04 implements IMU rotation roll, yaw, and pitch movements in firmware and web visualizer
2025-04-07 adds further example code for IMU to attempt to calculate abs position but no luck :( also adds piano demo
2025-04-08 more IMU tweaking
2025-04-13 tweaks imu to gamepad analog movement; updates web visualizer to handle multiple gloves and arm trackers
2025-04-22 updates Fusion archive files to latest
    [EIDON_FINGER.f3d, EIDON_THUMB.f3d]
2025-05-06 updates quaternion values to pass over HID as 16-bit values; updates web visualizer for 16-bit quat; updates IMU to use game rotation vector
2025-05-08 sorts devices with glove first
2025-05-10 revamp web viz style; adds dark mode; works out bunch of kinks with device connection and disconnect; consolidates device-list into sidebar input values list
2025-05-12 fixes view control buttons; disables debugging logs; adds chained mode
2025-05-13 makes first tracker arrow vector shorter (for hand); implements calibration buttons to reset/tar IMU with a remote command
2025-05-14 updates web viz to filter eidon tracker and glove vendor_id; updates glove firmware to use common vendor_id
2025-05-14 fixes removal of tracker arrows upon device disconnection; improves base deviceId created from pid-vid-name; ui tweaks
2025-05-14 adds alternate palm model for left hand
    [palm_lid_alt.stl]
2025-05-14 adds missing shim pio file from last commit and implements unique advertised device name... ex: Eidon Glove-XXXX
    [main.cpp]
2025-05-15 cleans up hid descriptor input report layout and corrects reportId
    [main.cpp]
2025-05-15 implements HID output report to externally trigger IMU reset
    [main.cpp]
2025-05-15 implements feature report and flash storage to set device specific configs like body posistion and enclosure color
2025-05-15 implements HID feature report for get/set device color
2025-05-16 updates web viz to detect device defined position; left/right, upper/lower
2025-05-16 cleans up style of device body posistion label tags
2025-05-19 adds lid models and renames existing lid model to palm_body; adds left hand model changes; implements button to reset IMU and to fire a button bit off to host
    [EIDON_GLOVE.3mf, EIDON_GLOVE_LEFT.3mf, EIDON_GLOVE_RIGHT.3mf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]
2025-05-19 implements status led indicator in firmware and updates lid models for charge led hole and power toggle switch
    [palm_lid.stl, palm_lid_blank.stl, palm_lid_left.stl]
2025-05-19 implements basic left vs right hand indicator in first bit of second buttons byte of data; moves boot button press to bit 1 of first buttons byte
2025-05-20 implements base device grouping and renders second arm tracker arrows
2025-05-20 maps glove buttons to hid buttons 1 and 2, then triggers calibration on trackers on the same arm when boot button is pressed
2025-05-27 flips quaternion forward direction since its mounted backwards within the glove; commits recent changes to web
2025-05-27 correctly flips IMU forward orientation
2025-05-28 fix: correctly oriented IMU quaternion so that yaw North is forward of the device based on datasheet
2025-05-31 Fix sensor calibration and add temporary ring/pinkie alignment offsets - Fix polynomial coefficients array and add manual +50 offset adjustments for ring and pinkie sensors. Add resetHallEffectCalibr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
2025-05-31 Improve BNO085 robustness and prevent startup failures - Replace infinite loop with retry mechanism in BNO085 initialization - Add availability tracking and helper functions for graceful degradation 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
    [main.cpp]
2025-05-31 Add persistent hall effect calibration with button reset - Store min/max angle calibration in flash memory to survive reboots - Auto-save calibration every 5 seconds when values change - Load saved c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
    [main.cpp]
2025-06-04 updates readme, adds images, updated base Fusion archive file; removes unused dep from firmware; tweaks MCP final angles to offset difference between pinky/ring and index/middle fingers MCP placement
2025-06-04 Simplify web app to focus on glove sensor data with fixed IMU orientation
    Major simplifications and fixes:
    🎯 **Core Focus**: Streamlined app to focus purely on glove sensor data
    - Removed complex arm/body modeling in favor of hand-only display
    - Simplified UI to show essential glove data: IMU orientation + finger joints
    - Removed unnecessary coordinate transformation options that caused confusion
    🔄 **Fixed IMU Orientation Issues**:
    - Resolved gimbal lock at 90° pitch where roll/yaw axes would flip
    - Found correct quaternion mapping: (x, z, -y, w) for device coordinate system
    - Added proper hand model base rotation (180° X + 180° Y) for correct palm orientation
    - Eliminated complex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
